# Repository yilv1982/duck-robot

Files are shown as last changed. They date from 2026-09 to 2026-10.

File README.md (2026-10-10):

# duck-robot

Microduck 小型双足机器人的个人复刻项目。**当前主线为方案 C（社区套件，飞特舵机路线，2026-10-09 定稿）**：选型采购、3D 打印、装配、系统部署与实机验证；强化学习训练在基础验证后再复现（方案 A 已存档，见下）。

进度流水、硬件到位记录与当前待办见 [PROGRESS.md](./PROGRESS.md)。

## 当前主线：方案 C（飞特路线）

- **执行机构**：飞特 HD-1910-C001 ×15（总线型，官方 robotd 有飞特补丁）
- **主控/总线**：microduck HAT（Radxa Zero 3W，板载 74LVC 半双工驱动接 UART2）+ imu_to_dxl v0.3 作总线从站（ID 200，双协议）
- **供电**：舵机/HAT/IMU 全部电池直通电压（电源板为可选转接件），拓扑见 [docs/power-architecture-v2.md](./docs/power-architecture-v2.md)
- **采购清单**：[BOM.md](./BOM.md)（已重写为 C 线；A 版存档于 [docs/bom-route-a-20260928.md](./docs/bom-route-a-20260928.md)）
- **PCB 打样**：[tools/jlc-order](./tools/jlc-order/README.md) —— 嘉立创开放平台全自动下单（计价→建单→审核→进度跟踪），2026-10-09 已实测下单并审核通过
- **IMU 刷机**：[flash/README.md](./flash/README.md)（DAPLink 接 J2 焊盘）
- 当前工作序列（IMU 刷机、banana_pcb 到板装配、舵机清点、HAT 验证）以 [PROGRESS](./PROGRESS.md) 待办为准；路线定稿理由与 C 线已知缺口见 PROGRESS「方案方向（2026-10-09）」。

## 并行参考库（只读）

三套开源资料按独立目录保存，**只读参考、不修改、不合并代码、硬件配置或采购清单**（2026-10-09 规则；历史混入的本地修改已提取到 [local-changes/](./local-changes/README.md)）：

| 方案 | 本地入口 | 参考内容 |
| :--- | :--- | :--- |
| A：帆哥教程 | [microduck-build-tutorial](./microduck-build-tutorial/README.md) | Pi Zero 2 W / OpenRB / XL330 路线（回退线，基线已存档） |
| B：fanhao375 复刻研究 | [microduck-replica](./microduck-replica/README.md) | 机械装配、电控与调试资料；兼论 XL330 与飞特路线 |
| C：jyg9 社区套件 | [microduck-community-kit](./microduck-community-kit/README.md) | **主参考**：imu_to_dxl / banana_pcb / dxl_hub 三块板、GD32 固件与升级工具、robotd 飞特补丁、HLS 舵机调试器 |

- 方案 B 遵循其 [LICENSE](./microduck-replica/LICENSE) 与 [NOTICE](./microduck-replica/NOTICE.md)：不同文件许可不同，不能整目录视为 Apache-2.0 或可商用；其打印 CAD 已迁往上游独立仓 [microduck-replica-cad](https://github.com/fanhao375/microduck-replica-cad)，本地 `cad/`、`print/` 不是完整打印包。
- 方案 C 缺口（`software/microduck_feetech/` 完整源码上游未推送、真机整定值仅可参考等）见 PROGRESS「方案方向」。

## 方案 A 回退线（存档）

A 线（XL330 + OpenRB + Pi Zero 2W）的完整步骤基线（阶段 0-7）、硬件约束（XL330/OpenRB 供电与板级电流限制）、仿真/镜像核查结论与 B 站视频笔记已整体移至 **[docs/route-a-baseline-20260928.md](./docs/route-a-baseline-20260928.md)**。相关入口：

- A 线 BOM 存档：[docs/bom-route-a-20260928.md](./docs/bom-route-a-20260928.md)
- 训练基线说明与验收证据：[docs/a-training.md](./docs/a-training.md)、[docs/a-training-validation.json](./docs/a-training-validation.json)
- 恢复 A 线训练环境前，需先把 [local-changes/microduck-build-tutorial/](./local-changes/microduck-build-tutorial/) 提取件按相对路径复制回位（`export_onnx.py` 内为旧机 WSL 路径，现机无 WSL，复用前须改写）。

## 致谢

感谢 [AI-FanGe/Microduck-build-tutorial](https://github.com/AI-FanGe/Microduck-build-tutorial)、[Rhoban/microban](https://github.com/Rhoban/microban)、[pollen-robotics/microduck](https://github.com/pollen-robotics/microduck) 及方案 B/C 上游作者的开源工作；各参考库内容以其自带许可为准。

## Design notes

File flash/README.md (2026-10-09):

# 刷机指南：把飞特固件烧进 ScrapMeta imu_to_dxl 板

目标板：**ScrapMeta `microduck-diy` imu_to_dxl v0.3**（32×22mm，丝印 `imu-to-dxl v0.3`，STM32G031F8P6 + LSM6DSV16X）——2026-10-09 用户确认手上绿板即此板。

要刷的固件：**replica 0.2.0 飞特版**（ID 200、@56 15 字节块、SCS/STS 协议）。预编译 HEX 已复制到本目录并通过作者公布的 SHA-256 校验（镜像 0x08000000 起 10,724 字节，`66bc7c53…938e`）。

> 引脚兼容性已逐脚核实（详见 `../docs/references/imu-to-dxl-variants-20261009/research.md`）：两板 PA0/PA1/PA2/PA3/PA4-7/PA11/PA12/PA13/PA14 功能一一对应；固件未用 INT2（ScrapMeta 板悬空无风险）；PB7 回显抑制脚在 ScrapMeta 板上是无害空操作。

---

## ⚠️ 供电红线（先读）

- 板上 LDO 是 **AP2210K-3.3，输入上限 5.5V**——这是 5V 供电设计。
- **刷机、调试、验收全过程中，VBATT 一律给 5V**（USB 5V 即可）。
- **绝对不要**把 2S 电池（7.2–8.4V）接到这块板的 VBATT——超 LDO 绝对最大值。将来在 8.4V 舵机总线上集成时，这块板的 VCC 必须从 5V 支路取电（与 jyg9 的 GD32 板 6–24V 输入不同）。

---

## 第 0 步：清点（你需要有什么）

| 物品 | 说明 | 没有？ |
|---|---|---|
| SWD 调试器 | **首选 CMSIS-DAP/DAPLink**（免驱）；ST-Link V2 也行（要装驱动，见排障） | 淘宝 ¥10–25 搜 "DAPLink" 或 "ST-Link V2" |
| SH1.0 7P 端子线 / BM07B 插座 | ⚠️ **实物板 J2 未焊插座，只有焊盘**（BM07B-SRSS-TB 是设计位号，出厂默认不贴）。方案 A：焊上 BM07B-SRSS-TB 座（约 ¥1-2）再插 SH1.0 7P 线（¥3，可复用）；方案 B：杜邦母对母线剪一头直接焊到 J2 焊盘（零采购，刷完剪掉） | 淘宝搜 "BM07B-SRSS-TB" / "SH1.0 7P 插头线" |
| 5V 电源 | USB 线（剪一头露出 +5V/GND）或面包板电源 | 现成的 USB 充电线即可 |
| 杜邦线母对母 | 4–6 根 | — |
| 万用表 | 核电压用 | — |

软件已全部备好（本目录）：OpenOCD 0.12.0、一键脚本、验收工具 imu200、Python 3.13 + pyserial（已装在 `C:\Users\elvis\AppData\Local\Programs\Python\Python313`）。**不需要装 Keil、不需要 ST 软件。**

## 第 1 步：接线（你做）

板子 **J2**（7P 调试座，板上丝印从 1 脚起：`3V3 / CLK / DIO / GND / TX / RX / RST`。⚠️ 实物板此处**未焊插座，只有焊盘**——按丝印把线逐根焊到焊盘上，或先焊上 BM07B-SRSS-TB 插座再用 SH 1.0 线）：

| J2 脚 | 丝印 | 接 DAPLink | 接 ST-Link V2 |
|---|---|---|---|
| 1 | 3V3 | **VTref**（电平参考，必接） | 3.3V 脚（作参考） |
| 2 | CLK | SWCLK | SWCLK |
| 3 | DIO | SWDIO | SWDIO |
| 4 | GND | GND | GND |
| 7 | RST | 可不接（连不上再接 NRST） | 同左 |
| 5/6 | TX/RX | 不接（验收阶段可选，见第 4 步） | 同左 |

板子供电（**J1**，EH 3P 总线座，丝印 GND/VBATT/DATA；J1/J3 并联插哪个都行）：

```
USB 5V  +  → J1-2 (VBATT)
USB 5V  −  → J1-1 (GND)
```

> 先用万用表确认你剪的 USB 线空载 5V 左右再接。接好后板上应有 3.3V（可用万用表量 J2-1 对 GND）。

**接好后的状态：DAPLink 插电脑 USB + 板子 5V 供电。**

## 第 2 步：烧录（你做，双击即可）

1. 双击 **`1-烧录-DAPLink.bat`**（ST-Link 用户用 `1-烧录-STLink.bat`）。
2. 看到这两行就是成功：
   ```
   ** Programming Started **
   ** Programming Finished **
   ** Verified OK **        ← 关键行
   ```
3. **给板子断电、再上电**（G0 芯片第一次烧写后的已知行为：软复位可能停在 ST 引导程序，断电重启一次即正常运行）。

脚本内容（其实就一条命令，出错时可直接看）：`openocd -f interface/cmsis-dap.cfg -c "adapter speed 200" -f target/stm32g0x.cfg -c init -c "reset halt" -c "program imu_to_dxl-0.2.0-feetech.hex verify" -c "reset run" -c shutdown`

## 第 3 步：接上总线（你做）

用 URT-2（或微雪转接板）做主机，跟板子对话：

```
URT-2 / 微雪适配器 TTL 总线三线 ──→ 板子 J1：
   GND  → J1-1 (GND)
   DATA → J1-3 (DATA)
   （VBATT 不从 URT-2 取，板子继续用自己的 USB 5V，共地即可）
```

URT-2 插电脑 USB，双击 **`2-查COM口.bat`** 找到它的 COM 号。

## 第 4 步：验收（你做，双击）

双击 **`3-验收-imu200.bat`**，输入 COM 号。它按主控真实代码的判据跑 **13 项检查**（ID 200 在线、@56 读 15 字节、四元数范数、陀螺量程、采样计数递增、不冻结、sync_read 时延……），全 PASS = 主控会认。

日志自动落在 `tools\imu200\logs\`（含原始收发十六进制），有问题把日志发我。

可选加分项：把 J2-5（TX）接任意 USB-TTL 的 RX（115200），能看到 replica 固件的调试日志。

## 排障

| 症状 | 处理 |
|---|---|
| DAPLink 方式报 `no CMSIS-DAP device found` | 换 USB 线/口（有些线只充电）；设备管理器看有没有 HID 设备 |
| ST-Link 报 `libusb_open() failed` / 找不到 | ST-Link 需要 WinUSB 驱动：装 [Zadig](https://zadig.akeo.ie/) → Options→List All Devices → 选 ST-Link → 目标驱动选 **WinUSB** → Replace Driver（约 30 秒）。换回 ST 官方软件时需重装 ST 驱动 |
| 连上但 `target halted` 报错/读不到 IDCODE | 检查 SWDIO/SWCLK 有没有接反；把 J2-7 (RST) 也接到调试器 NRST；脚本已用低速 200kHz，仍不行降到 100（编辑 bat） |
| `Programming Finished` 但 `Verified` 报错 | 重新烧一次；再不行把 bat 里 `verify` 后加 `reset halt` 前多等——一般不出现 |
| 验收某项 FAIL | 把 `tools\imu200\logs\` 最新日志发我，逐条判 |

## 文件清单

| 文件 | 说明 |
|---|---|
| `imu_to_dxl-0.2.0-feetech.hex` | 待刷固件（已过 SHA-256 校验；来源 replica 仓库 Build/，参考库只读所以复制出来） |
| `verify_hex.py` | 重跑完整性校验：`python verify_hex.py` |
| `1-烧录-DAPLink.bat` / `1-烧录-STLink.bat` | 一键烧录（program + verify + reset run） |
| `2-查COM口.bat` | 列串口 |
| `3-验收-imu200.bat` | 总线 13 项验收 |
| `tools/xpack-openocd-0.12.0-7/` | OpenOCD（xpack 构建，内置 stm32g0x 支持，无需器件包） |
| `tools/imu200/` + `tools/servo-web/` | 验收工具（来自 replica 仓库，复制出来用；`imu200.py demo` 可离线自测） |

## 边界（诚实清单）

- replica 0.2.0 固件**作者自述"真总线和舵机尚未实测"**（其主机测试与模拟总线验收全过，2026-09-22 已烧进其开发板工作正常）。本板刷完后 `imu200 check` 全 PASS 才算第一步验收；DE 释放时序、绝对 T_resp 等需逻辑分析仪的项可后置。
- 刷机会覆盖板上原有固件（ScrapMeta 的 DXL 2.0 版，如预刷过）；想刷回去：源码在参考库 `microduck-diy`（上游仓库），ScrapMeta 自带 `make g031` 构建与烧录脚本。
- 固件不写 Option Bytes、不写配置进 Flash（作者文档声明），刷写动作可逆、无 brick 风险（SWD 始终在）。

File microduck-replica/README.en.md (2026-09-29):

# Microduck Replica

**English** · [简体中文](README.md)

> A third-party reconstruction study of [Pollen Robotics' Microduck](https://pollen-robotics.com/microduck/).
> Assembly drawings, exploded views, CAD-importable assemblies, and a complete
> electronics teardown — all derived from publicly released files and source code.

Microduck is a 25 cm, 737 g bipedal robot duck driven by 15 Dynamixel XL330 servos
(14 under policy control) that learns to walk with reinforcement learning.

Its **software is open source (Apache-2.0)**. Its hardware is **partly** open:

- ✅ **The RPI Robot HAT board is fully published** — [`pollen-robotics/elec_RPI_Robot_HAT`](https://github.com/pollen-robotics/elec_RPI_Robot_HAT)
  (Apache-2.0): KiCad 9 project, Gerbers, BOM, pick-and-place and STEP. **You do not need to redraw this board.**
- ❌ **The `imu_to_dxl` board is not published** — no public project exists anywhere; the reconstruction
  in this repo is the only one available.
- ❌ **No editable mechanical CAD**, no whole-robot BOM, no assembly documentation. Pollen Robotics
  [told the press not to call it "open-source hardware" (for now)](docs/社区动态.md).

> 📌 **Correction (2026-09-03)**: this document previously stated "its hardware is not [open], no PCB
> schematics". **That was wrong** — it searched only `pollen-robotics/microduck` and missed the
> organisation's `elec_`-prefixed hardware repositories.

But two public artifacts turn out to be enough:

1. **`microduck_rl` ships the full MJCF model and 47 STL meshes.** The MJCF contains the
   complete kinematic tree — which part mounts to which, relative positions accurate to
   0.1 mm, joint axes, travel limits, masses and inertia tensors.
2. **The Rust runtime is open source, and a runtime that drives real hardware must
   hard-code device paths, I²C addresses, register offsets, baud rates and protocols.**
   The code *is* the datasheet.

This repository is what falls out of reading both.

> ✅ **Independently verified.** On 2026-08-31, [@tspy](https://x.com/tspy/status/2094249218735300630)
> published a hardware teardown on X (169 likes) that matches this repository's
> conclusions exactly — including the critical one: **the main board is a Radxa Zero 3W**.
> Two independent paths, one answer. See [Community Intelligence](docs/社区动态.md).

---

> **Models and print files: [microduck-replica-cad](https://github.com/fanhao375/microduck-replica-cad).** Select the Feetech or XL330 version there. Outdated printable STLs have been removed from this repository.

## Two tracks — pick one

This repository covers two servo choices. **Mechanics, electronics and software all differ**, so decide before building:

| | Original · Dynamixel XL330 | Feetech · HD-1910 |
|---|---|---|
| **Servos** | XL330-M288-T ×15 | HD-1910-C001 ×15 — half the price, 2.5× the torque |
| **Voltage** | rated 6 V, run at 6.6–8.2 V, **37% over** | rated 4–8.4 V, within spec; a full pack sits at the 8.4 V ceiling |
| **Printed parts** | [CAD repository · XL330](https://github.com/fanhao375/microduck-replica-cad) | [CAD repository · Feetech](https://github.com/fanhao375/microduck-replica-cad); mating parts are not interchangeable |
| **Editable CAD** | [CAD repo v1.1](https://github.com/fanhao375/microduck-replica-cad/releases/tag/v1.1) | [CAD repo v2.1](https://github.com/fanhao375/microduck-replica-cad/releases/tag/v2.1), files carry an `-FT` suffix |
| **Electronics** | official HAT + [`imu_to_dxl`](hardware/imu_to_dxl/) | same; servo connectors are 2.0 mm (official 2.5), `imu_to_dxl` has J4/J5 at 2.0 |
| **Software** | official runtime runs as-is | different bus protocol, swap the protocol module — [adaptation architecture](software/飞特适配架构.md) (zh); policy retrained for HD-1910 — [training data checklist](docs/HD-1910训练前数据清单.md) |
| **Status** | paper analysis + first prints | Assembled and stood up (09-18); **HAT received, camera capture passed on official B1** (09-28). Returning to the project image for retesting; mouth servo temporarily reassigned to ID 21 |

The selection argument is in [Actuator Selection](docs/actuator-selection.en.md). This repo's main line is Feetech; the original track is documented just as fully.

---

## Community

A WeChat group for people working on the same thing — build progress, pitfalls, sourcing.

The code below is for **Duck Replica Group 9** (WeChat disables QR joins once a group reaches 200 members).

<div align="center">
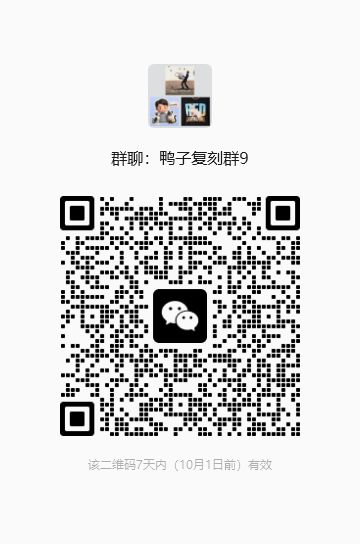
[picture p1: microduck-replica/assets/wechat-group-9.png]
Duck Replica Group 9 WeChat QR code
  
  <br>
  <sub><b>Duck Replica Group 9 · expires 2026-10-01</b> — WeChat group codes are valid for 7 days<br>
  If it has expired, open an <a href="https://github.com/fanhao375/microduck-replica/issues">issue</a> and I will post a fresh one</sub>
</div>

## Latest

**2026-09-28 — HAT and camera bring-up:** The HAT has arrived and been fitted to the board. After the camera ribbon orientation/contact was corrected, the Radxa Camera 8M219 was identified and **40 frames at 1920×1080** were captured on official Bookworm B1. The next step is to return to the project Armbian image and repeat the test with the corrected wiring. Sustained frame rate, all HAT functions and robot walking remain unverified. See the [wiring reference and test record](tools/radxa/摄像头调试记录-20260928.md) (Chinese).

<table>
<tr>
<td width="50%" valign="top">

### 🔌 Electronics · all 15 servos powered up in the assembled duck, and it stands (2026-09-18)

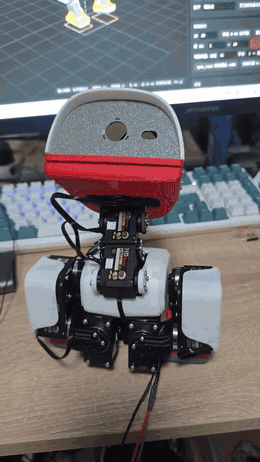
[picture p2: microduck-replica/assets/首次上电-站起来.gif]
First power-on: standing up from the tucked pose (click for the 30 s video)
<p align="center"></p>

First time the assembled duck was on the bus: URT-2 over USB, 7.4 V into V1, **all 15 HD-1910 online, 0 timeouts, 0 checksum errors**, one sync_read of 15 servos in 4.8 ms.
Driven from the new [web servo console](tools/servo-web/) in this repo: sliders, saved poses, sequences, a 3D model that follows the real robot and a live centre-of-mass marker against the foot support.
Above, it stands up from the tucked pose **by itself**, then sits back down. **First step of the Feetech software path works**; the hardware plan holds.

The above is the 09-18 test. As of 09-28, the failed ID 21 servo has been replaced with the former mouth servo (ID 34); the operator confirmed centre calibration at 2048, and the mouth is temporarily missing. The old “all 15 online” result is not the current configuration. Feetech-protocol [`imu_to_dxl` firmware 0.2.0](hardware/imu_to_dxl/firmware/) is available; physical bus testing is still pending.

**[Web servo console](tools/servo-web/)**　·　
**[Debug log](调试记录.md)** (zero pose, joint direction, stance pitfalls)　·　
[Pitfalls](踩坑记录.md#工具) (URT-2: USB first, then servo power)　·　
[Feetech adaptation architecture](software/飞特适配架构.md) (zh)

</td>
<td width="50%" valign="top">

### 🔨 Mechanical · Feetech HD-1910 build is assembled

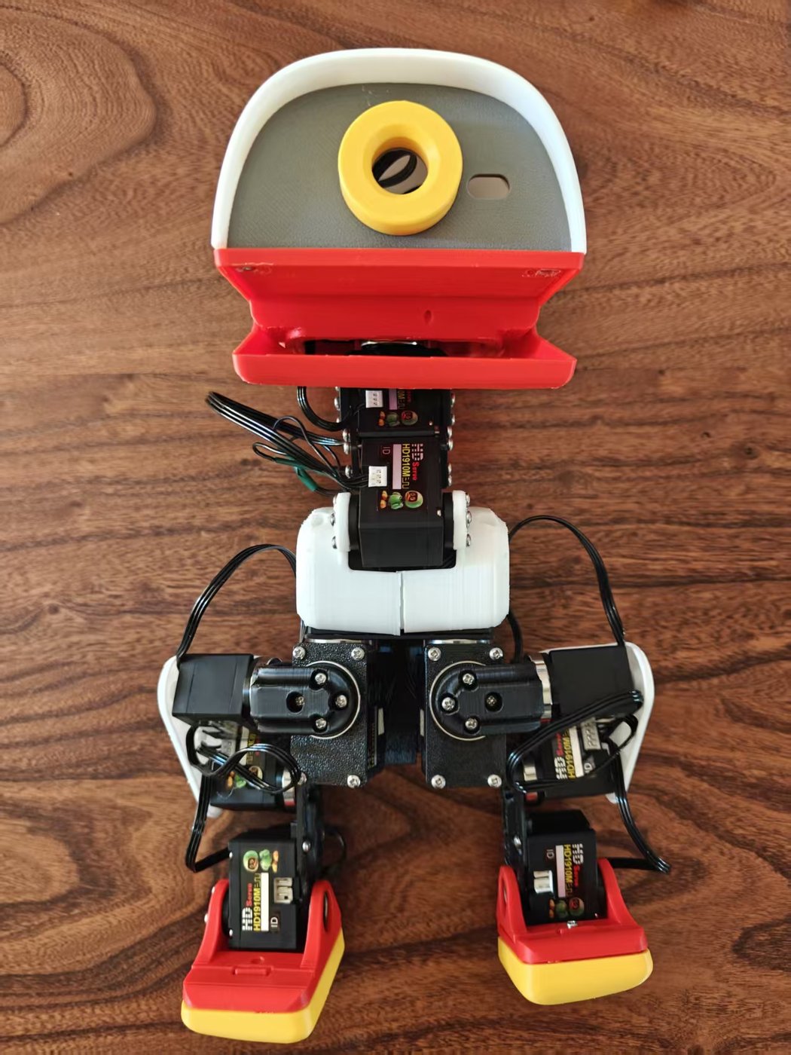
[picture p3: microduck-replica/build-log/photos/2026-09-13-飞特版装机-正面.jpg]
Feetech HD-1910 build


**All 15 Feetech HD-1910 servos configured and mounted.** Not the official XL330 — half the
price, 2.5× the torque, running inside its rated voltage; the path argued in
[Actuator Selection](docs/actuator-selection.en.md), now physical.

**The HD-1910 horn protrudes where the XL330's is recessed**, so the 8 parts that mate with
horns were remodelled and reprinted. The editable SolidWorks drawings have an FT variant
(`-FT` suffix) with what changed and why.

**[Build Log](BUILD-LOG.en.md)**　·
**[Feetech-variant SolidWorks drawings](https://github.com/fanhao375/microduck-replica-cad)**　·
**[Models and print files](https://github.com/fanhao375/microduck-replica-cad)**　·
[Debug Log](调试记录.md)　·
**[BOM with purchase links](https://github.com/fanhao375/microduck-replica-cad#装配-bom)**　·
[Print downloads](print/)
</td>
</tr>
<tr>
<td width="50%" valign="top">

### 💻 Software · web console driving 15 servos over the serial bus

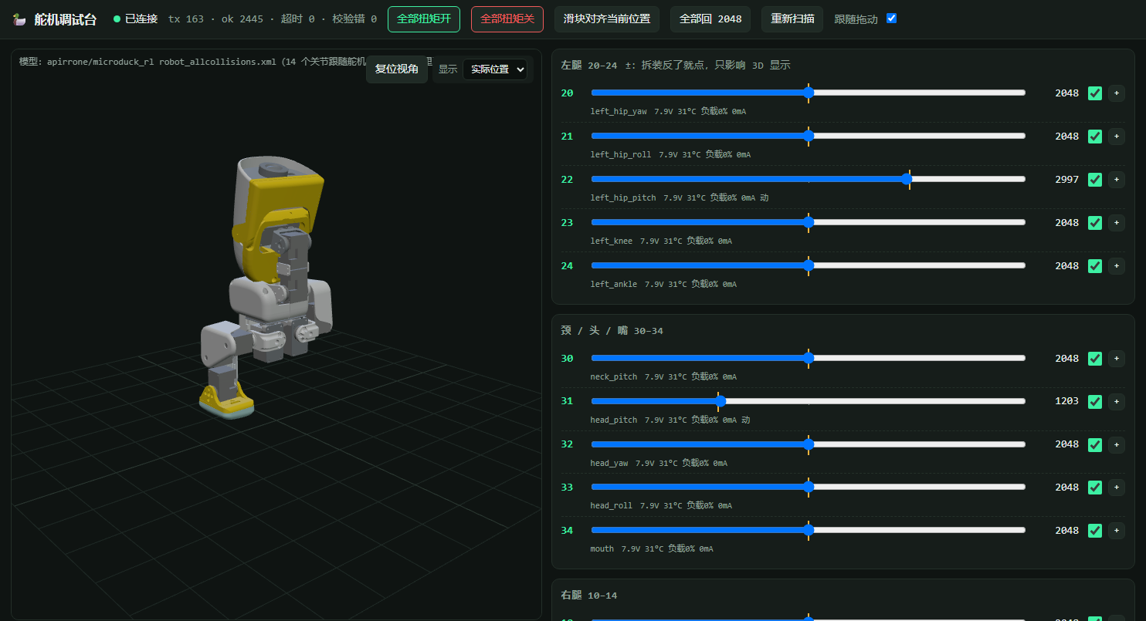
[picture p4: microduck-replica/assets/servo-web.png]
Web console: sliders, 3D duck, CoM projection
<p align="center"></p>

Drag a slider in the browser and the servo moves; the 3D duck follows, and the centre-of-mass
projection shows live whether it still falls inside the foot support polygon. Save poses, run
sequences, calibrate the zero in one click, dump every register, measure bus timing — this is the
tool used for assembly and bench acceptance.

The backend does not use the Feetech SDK: [`feetech.py`](tools/servo-web/feetech.py) speaks the
2026 protocol manual directly in about a hundred lines. It ships with a **packet-level servo
simulator**, so calibration, ID changes and register writes are self-tested with no hardware attached.

`FeetechIo` for the official runtime (the `RobotIo` seam, rustypot protocol v1) is written and
waiting on the zero calibration before it goes on the board.

**[Web console](tools/servo-web/)**　·　
**[Feetech port architecture](software/飞特适配架构.md)**　(Chinese)　·　
[Feetech official docs](docs/飞特资料/)

</td>
<td width="50%" valign="top">

### 🧠 Algorithms · public 1910 M6 parameter integration

The Feetech simulation baseline adopts the **1910 BAM M6 actuator parameters published by
[LuwuDynamics/xgoduck_rl](https://github.com/LuwuDynamics/xgoduck_rl)**. Thank you to LuwuDynamics
for sharing them. These parameters were not independently identified by this replica project.
The [provenance record](docs/HD-1910-M6参数来源.md) includes the pinned source revision,
original-file checksum and Apache-2.0 license.

The complete training project is included in **[`software/training/`](software/training/)**:
one clone includes the source, actuator parameters and simulation models. See the
[run guide and controller initialization fix](software/training/docs/hd1910-baseline.md).
Training builds on [Pollen Robotics/microduck_rl](https://github.com/pollen-robotics/microduck_rl)
and [Rhoban/BAM](https://github.com/Rhoban/bam). Integration tests and a short training check
have passed; there is no walking policy validated on this replica yet. Hardware testing still
needs joint calibration, IMU/runtime integration, and checks of actual mass/inertia and servo response.

**[HD-1910 pre-training data checklist](docs/HD-1910训练前数据清单.md)**　·　
[Actuator selection](docs/执行器选型.md)

</td>
</tr>
</table>

---

## 🔨 Build Progress

> This repository states repeatedly that simulation STLs are not manufacturing files.
> **The build log is the test of that claim.** The result gets recorded either way.

**→ [Build Log](BUILD-LOG.en.md)**

---

## 🦆 Contributions from the flock

This repo is not one person's work. Merged code and bench-verified findings are credited here.

| Who | What they contributed |
|---|---|
| [@yoyojacky](https://github.com/yoyojacky) | **A Rust test tool for Feetech servos** ([PR #27](https://github.com/fanhao375/microduck-replica/pull/27), merged). A minimal STS/SCS protocol implementation of his own (framing, checksum, ping, register read/write, status parsing). The CLI scans the bus with a progress bar, reads status, moves a servo to a position, and runs single or batch tests that report position error, peak current, peak load, voltage and temperature, with a PASS/FAIL verdict — one command gives you a bench acceptance table → [`tools/sts3215Servo_testtool/`](tools/sts3215Servo_testtool/) |
| [@Abo1ish](https://github.com/Abo1ish) | **IMU board firmware + attitude view in the debug console** ([PR #32](https://github.com/fanhao375/microduck-replica/pull/32), merged). A base STM32G031 firmware for the imu_to_dxl board that Pollen never open-sourced, verified on real hardware, with host-side tests and a [`VALIDATION.md`](hardware/imu_to_dxl/firmware/VALIDATION.md) that is clear about its limits → [`hardware/imu_to_dxl/firmware/`](hardware/imu_to_dxl/firmware/). He also streams the IMU attitude over J-Link into the web debug console, so the 3D duck's body turns with the real board (`--imu-jlink`, or `--imu-demo` with no hardware) → [`tools/servo-web/`](tools/servo-web/) |
| A member of the WeChat group | **Boot recipe for the Radxa Zero 3W V1.12J.** On this batch (WiFi changed to AIC8800DS2), swapping in Radxa's bootloader is not enough. He found by testing that the device tree has to come from Radxa too: **B1 bootloader + B1 DTB + Armbian 6.1.115 kernel + Trixie userland**, and got it booting → written up in the [pitfalls log](踩坑记录.md#软件) and the [image guide](tools/radxa/镜像使用说明.md) (both Chinese) |

### Projects from the flock

Some people build duck-related things in their own repos. The good ones get a shout-out here:

| Project | Author | What it does |
|---|---|---|
| [microduck-color-studio](https://github.com/LathamZ/microduck-color-studio) ([live demo](https://lathamz.github.io/microduck-color-studio/)) | [@LathamZ](https://github.com/LathamZ) | **A 3D color studio for the duck: settle the colors in your browser before you print.** Color each of the 70 parts, pick a material (PLA / matte / PETG / metallic / carbon fiber / TPU) and lighting to preview. Enter the filaments you already own and it recommends palettes from your stock (use what you have / add one color / acrylic accents). You can also import your own 3MF (e.g. the Feetech version) and export a **colored multi-plate 3MF** plus per-part STLs, with presets for Bambu P1S / A1 mini / H2D. Chinese and English UI, works on mobile |
| [MICDUCK_FTHD1901_REBUILD](https://github.com/fengj4780-sudo/MICDUCK_FTHD1901_REBUILD) | [@fengj4780-sudo](https://github.com/fengj4780-sudo) | **Feetech-build structural rework with optional CNC reinforcement.** Builds on our [editable SolidWorks drawings](https://github.com/fanhao375/microduck-replica-cad): adapted to the Feetech servo (written as HD1901 in that repo; the part files are HD-1910-C001), weak parts reinforced, assembly interferences fixed and some broken models repaired. **Five leg parts can be made as CNC parts** for better load paths (still being prototyped; the author estimates about ¥45 for all five including shipping); printing them instead also works and is stronger than the original. Includes a one-click 3MF (Bambu H2D, 0.4 mm, 5 plates) and the reworked SolidWorks drawings (Chinese) |

Built something for the duck (a tool, tutorial, mod, policy…)? Open an issue with the link and we'll add it.

Want to join in: open an [issue](https://github.com/fanhao375/microduck-replica/issues) or send a PR.
Hardware, firmware, algorithms, documentation, measured data — all of it counts. **Measured data especially**: the rule in this repo is that results get recorded honestly, positive or negative.

---

## Exploded Assembly View

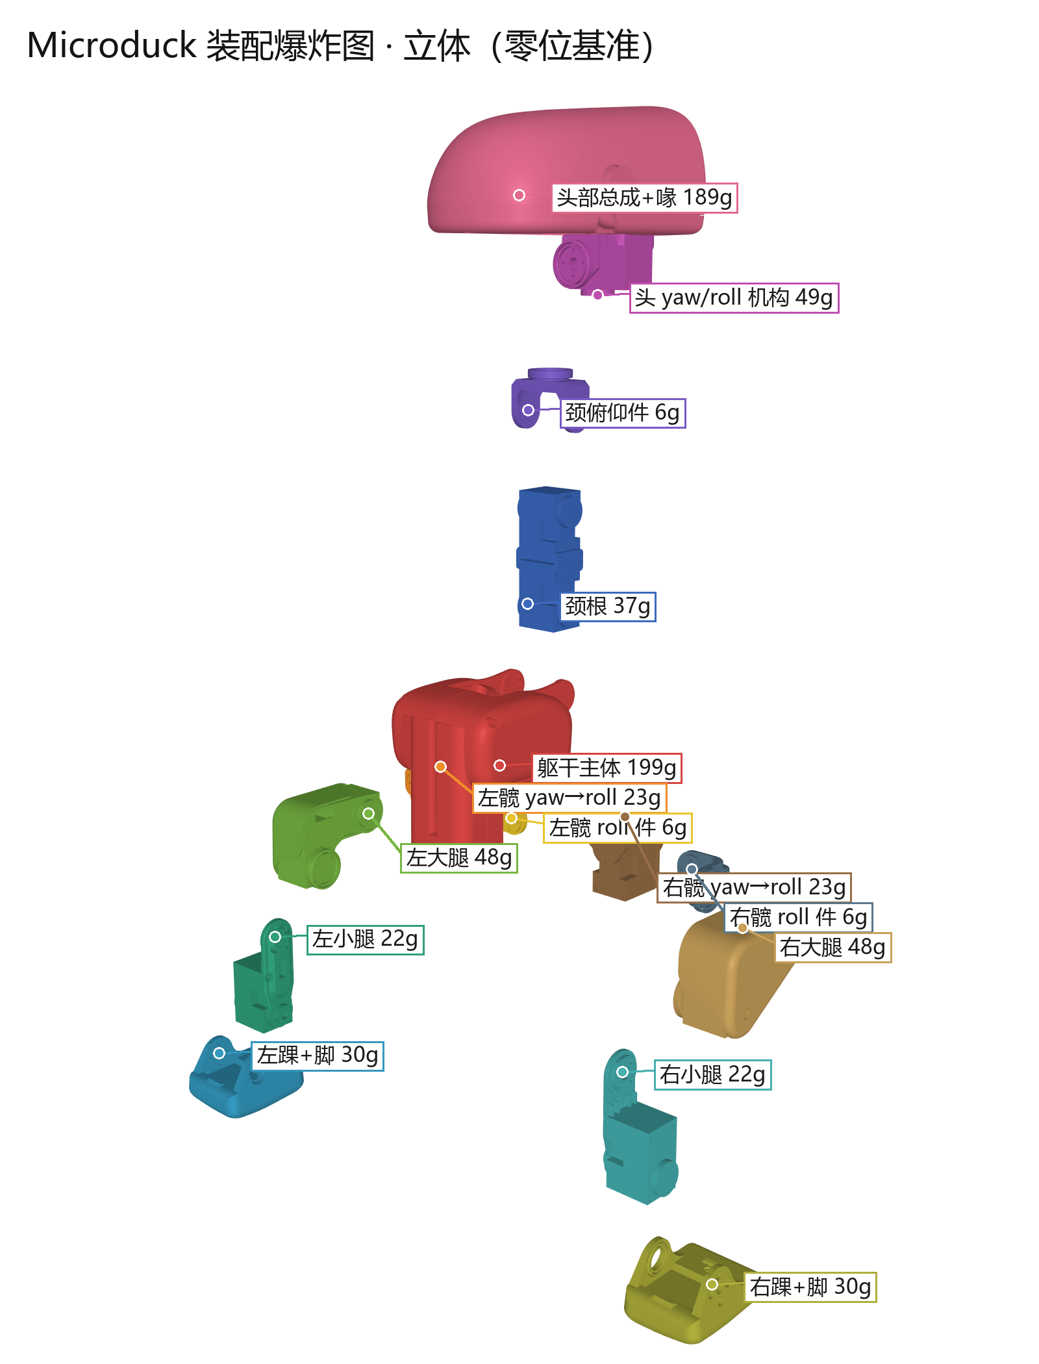
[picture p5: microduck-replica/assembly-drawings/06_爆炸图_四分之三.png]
Exploded view


Seven drawings under `assembly-drawings/`:

| File | Contents |
|---|---|
| `01_正面` `02_侧面` `03_背面` `04_四分之三` | Front / side / rear / isometric, assembled, natural colors |
| **`05_爆炸图_侧面`** | 15 parts exploded along the kinematic chain, labeled with names and masses |
| **`06_爆炸图_四分之三`** | Isometric — shows the left/right leg mirroring clearly |
| `07_分色对照_装配态` | Assembled state in the same color coding, for cross-reference |

## Assembly Structure

```
Trunk 199 g
├─ L hip yaw→roll 23 g → L hip roll 6 g → L thigh 48 g → L shin 22 g → L ankle+foot 30 g
├─ Neck base 37 g → Neck pitch 6 g → Head yaw/roll 49 g → Head assembly + beak 189 g
└─ R hip yaw→roll 23 g → R hip roll 6 g → R thigh 48 g → R shin 22 g → R ankle+foot 30 g

Total 737.2 g   Envelope 144 × 141 × 264 mm
```

The trunk and the head weigh almost the same (199 g vs 189 g) — **the head is a quarter of
the whole robot and the center of mass sits high**, which explains why its walking policy
is hard to train.

## Joint Parameters

Five DoF per leg, four for neck and head — **14 under policy control**.
The robot actually carries **15 Dynamixel XL330**: the 15th drives the beak through a
passive linkage and never enters the action space.

| Joint | Travel |
|---|---|
| `hip_yaw` | −25° … +30° |
| `hip_roll` | ±22° |
| `hip_pitch` / `knee` / `ankle` / `head_pitch` | ±90° |
| `neck_pitch` | −90° … +60° |
| `head_yaw` | ±170° |
| `head_roll` | ±25° |

## 📋 Bill of Materials

**What to buy and how many** — [`BOM.en.md`](BOM.en.md)

15 servos, 14 bearings, ~325 fasteners, 2 boards to fabricate. Quantities are counted from geom
references in the upstream MJCF (38 mesh types / 75 instances), not estimated. Includes a per-board
parts list with LCSC numbers.

> ⚠️ Two corrections in there that stop you buying the wrong thing: **the battery is an NP-F550,
> not an F970**, and **the XL330 is run over-voltage**.

## Print files and CAD assemblies

**Download models from [fanhao375/microduck-replica-cad](https://github.com/fanhao375/microduck-replica-cad).** SolidWorks, STEP, print projects, assembly BOMs and installation instructions are maintained together there.

| Servo version | CAD release checked on 2026-09-28 |
|---|---|
| Feetech HD-1910 | [v2.1](https://github.com/fanhao375/microduck-replica-cad/releases/tag/v2.1) |
| Dynamixel XL330 | [v1.1](https://github.com/fanhao375/microduck-replica-cad/releases/tag/v1.1) |

The old `print/` parts and `cad/` assembly STLs came from upstream simulation geometry and did not include the physical CAD changes. Those files have been removed; the directories now contain download pointers. **Do not mix the two servo versions or print simulation/web-viewer meshes from this repository.**

The CAD repository's older 09-15 3MF does not include the v2.1 combined wheel. Check the attachment version; see [printing notes](print/README.en.md). CAD modelling and assembly documentation are by **机械行者Robo**, with attribution and licensing in the CAD repository.

---

## Electronics, Reverse-Engineered from the Runtime

<div align="center">
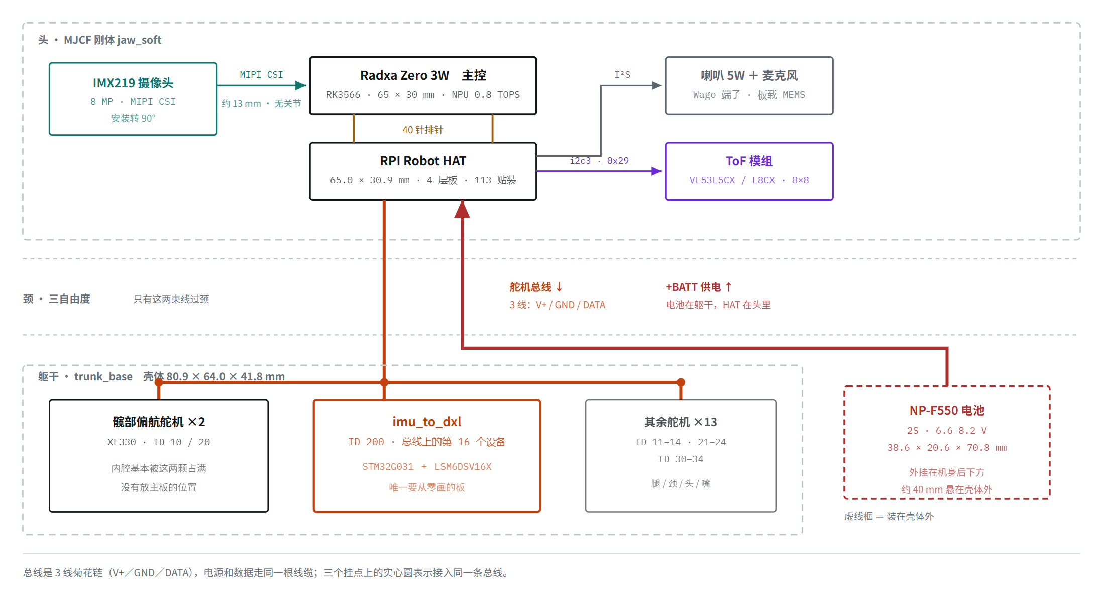
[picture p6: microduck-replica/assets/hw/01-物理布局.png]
Microduck electronics overview: where each board sits
  
  <br>
  <sub><b>Physical layout of the five modules.</b> Dashed grey = physical region, solid = module,
  dashed red = mounted <b>outside</b> the shell.<br>
  <b>Orange</b> is the servo bus (top-down), <b>red</b> is battery power (bottom-up).<br>
  The one thing people get wrong: <b>the compute board, the HAT and the camera are all in the head</b> —
  the camera sits ~13 mm from the board centre with no joint between them,<br>
  so the MIPI ribbon never crosses the neck. What does cross it is the servo bus and the power line.<br>
  <a href="docs/硬件入门.md">Full diagram set (Chinese) →</a>　·　<a href="assets/hw/Microduck硬件图集.pdf">Download PDF (7 diagrams, A3)</a></sub>
</div>

**One 1 Mbps TTL serial bus does everything.**

```
                Radxa Zero 3W (RK3566) · Armbian
                  ├── UART2  1 Mbps TTL half-duplex ── 15× XL330 + imu_to_dxl (ID 200)
                  ├── I2C3   400 kHz (pins 3/5) ────── AIC3104@0x18 · ToF@0x29 · BMI088 (unused)
                  ├── I2S3   12.288 MHz ────────────── audio
                  ├── MIPI CSI ─────────────────────── IMX219 (I2C@0x10, mounted upside down)
                  ├── Bluetooth ────────────────────── gamepad / phone app
                  ├── Wi-Fi ────────────────────────── WebRTC
                  └── USB-C ────────────────────────── power + maskrom
```

| | |
|---|---|
| **Main board** | **Radxa Zero 3W** — an off-the-shelf module, *not* a custom carrier |
| SoC | RK3566, quad Cortex-A55, Mali-G52, 0.8 TOPS NPU, 1 GB RAM / 32 GB eMMC |
| **Servo bus** | **Single-wire half-duplex TTL** — *not* RS-232, *not* RS-485. Dynamixel Protocol V2 @ 1 Mbps on `/dev/ttyS2` |
| **Custom board 1** | **`imu_to_dxl` v2** — an LSM6DSV16X that speaks Dynamixel: bus ID 200, register 124, a 12-byte block read in the *same* `sync_read` as the servos |
| **Custom board 2** | **RPI Robot HAT** — TLV320AIC3104 @ 0x18, a dormant BMI088, a Stemma header for the ToF. **Published by Pollen** ([`elec_RPI_Robot_HAT`](https://github.com/pollen-robotics/elec_RPI_Robot_HAT)) |
| Battery | Sony NP-F550, 2S Li-ion. **No fuel gauge, no ADC** — pack voltage is read from what the servos report as their own supply |
| Sensors | LSM6DSV16X IMU · VL53L5CX/L8CX 8×8 ToF · IMX219 (Pi Camera v2) |

The `imu_to_dxl` design is the elegant part: the IMU is not on I²C. It presents itself as a
Dynamixel slave, so orientation arrives in the same bus transaction as the joint states —
no second bus, no host-side sensor fusion (the LSM6DSV16X's on-chip SFLP block emits a game
rotation quaternion and estimates its own gyro bias).

**Full detail:** [Hardware Teardown](docs/hardware-teardown.en.md) (English) ·
[Spec Sheet](docs/硬件规格速查.md) (Chinese)

---

## Can You Actually Build One?

| | Status |
|---|---|
| Part geometry | ✅ 47 STLs |
| Assembly relationships | ✅ 0.1 mm accurate, drawings produced |
| Joint axes / travel | ✅ all 14 |
| Mass / inertia | ✅ all 15 bodies |
| Servo model | ✅ Dynamixel XL330 × 15 |
| Bearings | ✅ Ø22×16×4 and Ø15×10×3 |
| Battery / sensors | ✅ NP-F550 2S, IMX219, VL53L8CX, LSM6DSV16X |
| Main board | ✅ **Radxa Zero 3W, off the shelf** |
| **HAT board** | ✅ **Officially published** — KiCad + Gerbers + BOM → [`elec_RPI_Robot_HAT`](https://github.com/pollen-robotics/elec_RPI_Robot_HAT) |
| **`imu_to_dxl` board** | ⚠️ Not published; must be redrawn. Protocol and register layout fully recovered |
| **Fastener list** | ✅ Reverse-engineered from hole features → M2 system |
| **Cable routing** | ❌ Nothing published |
| Control software | ⚠️ Rust runtime is Apache-2.0 and **runs as-is on the same main board** |

⚠️ **Simulation STLs are not manufacturing files.** Simulation only needs outer shape and
inertia — it guarantees nothing about fit tolerances, threads, heat-set insert bosses or
cable clearance. Printing these directly will most likely not assemble.

💰 **Building one probably costs more than buying one — but how much more depends entirely on
your channel.** Fifteen XL330s run about **$359** at ROBOTIS international, **$412** at ROBOTIS US,
and **€603–629** in Europe inc-VAT — anywhere from slightly under the robot's retail price to well
above it. Add the compute module, battery, two boards to fabricate and filament, and it is certainly
more. Full costing: [BOM.en.md](BOM.en.md).

**The conclusion has been revised** from "the mechanics are copyable, the electronics are a wall"
to **"the whole robot is reproducible"** — the main board is an off-the-shelf module, and the custom
boards' function and protocol have been fully recovered from source.
See [Hardware Teardown](docs/hardware-teardown.en.md).

---

## The Realistic Path

Skip 100% replication and go **"copy the mechanics, build your own electronics"**:

| | Approach |
|---|---|
| Mechanics | Select the matching servo version in the [CAD repository](https://github.com/fanhao375/microduck-replica-cad) |
| Servos | XL330 × 15, off the shelf |
| Main board | **Radxa Zero 3W**, same as the original |
| IMU board | Roll your own `imu_to_dxl`: LSM6DSV16X + a small MCU + half-duplex transceiver. The protocol is fully documented here |
| HAT | **Order the official Gerbers** (4-layer); or skip it entirely if you don't need audio |
| Software | Same main board → the official Rust runtime runs unmodified |
| Policies | The nine shipped ONNX policies work; retrain with [microduck_rl](https://github.com/pollen-robotics/microduck_rl) if you change hardware |

## Three Pitfalls Worth Knowing

1. **Armbian runs a login console on UART2.** `serial-getty@ttyS2` holds the port —
   `systemctl mask` it. Pollen found this with `fuser -v /dev/ttyS2`.
2. **i2c3 collides with the FUSB302.** Using the hardware I²C on header pins 3/5 costs you
   USB-C PD negotiation (plain 5 V charging still works).
3. **The NPU ships disabled** in Armbian — flash the overlay and reboot to run RKNN models.

---

## Ecosystem Map

Microduck material is scattered across several GitHub orgs and three HuggingFace resource types —
**the official hardware repos are especially easy to miss**. [`docs/ecosystem.en.md`](docs/ecosystem.en.md)
annotates every official repo, simulator, policy, dataset and community project with what it is and
what it is good for.

## Documentation

| Document | Contents |
|---|---|
| [**Hardware Spec Sheet**](docs/硬件规格速查.md) | One-page reference — block diagram, part numbers, bus parameters, build list, pitfalls |
| [**Hardware Primer**](docs/硬件入门.md) | **Board by board** — what each of the five modules does, how one 20 ms control tick flows, what changes on the Feetech route, and a closing section on **five checks to run before you replicate** |
| [**Electronics Sourcing (CN)**](docs/电控采购清单.md) | Taobao links with verified availability — main board, camera, ToF, power, both PCBs, cabling and the debug adapter |
| [**Mechanical Sourcing (CN)**](docs/机械采购清单.md) | Bearings, M2 fasteners, heat-set inserts and the insertion tip, thread locker, filament |
| [**Hardware Teardown**](docs/hardware-teardown.en.md) 🇬🇧 | **Full derivation with evidence citations — the main board, both custom boards, bus protocol, sensors, power** |
| [**Actuator Selection**](docs/actuator-selection.en.md) 🇬🇧 | XL330 parameters, BAM M6 config, five calibrated PD sets, backlash modeling — plus **why closed-loop steppers do not work here, what swapping to a Feetech STS3215 actually costs** (737 g vs 2107 g, measured), and a **cross-comparison of same-class servos** including a deep assessment of the Unitree S288 |
| [**Fastener Reconstruction**](docs/fastener-reconstruction.en.md) 🇬🇧 | Hole-feature scan across 47 STLs → M2 system and purchase quantities |
| [Community Intelligence](docs/社区动态.md) | X / GitHub signals, independent verification, noise and scam warnings |
| [Progress](PROGRESS.md) | Status, decisions, open work |

> 🇬🇧 marks documents available in English. The rest are Chinese-only for now — their
> tables, part numbers, addresses and diagrams are readable without it, and machine
> translation handles the prose well.

## Reproducing This

```bash
# 1. Fetch upstream for the drawing scripts below (training is already in software/training/)
bash scripts/fetch_upstream.sh

# 2. Regenerate the drawings
python scripts/render_assembly.py upstream/microduck_rl assembly-drawings

# 3. Export upstream assembly previews for analysis (not manufacturing)
python scripts/export_assembly_stl.py upstream/microduck_rl analysis-output/cad-upstream

# 4. Re-scan hole features
python scripts/analyze_holes.py upstream/microduck_rl/src/mjlab_microduck/robot/microduck/assets
```

Requires `mujoco`, `numpy`, `pillow`, `scipy`. Rendering needs a working OpenGL context.

## License

- `scripts/` — Apache-2.0
- `assembly-drawings/` and retained simulation meshes — **CC BY-SA-NC 4.0**. Upstream 3D models are CC BY-SA-NC;
  ShareAlike requires derivatives to carry the same license. **Non-commercial only.**

See [NOTICE.md](NOTICE.md). Not affiliated with or endorsed by Pollen Robotics.

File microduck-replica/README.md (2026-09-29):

# Microduck 复刻

**简体中文** · [English](README.en.md)

> **模型与打印文件统一入口：[microduck-replica-cad](https://github.com/fanhao375/microduck-replica-cad)。** 飞特 / XL330 请选对应版本；本仓旧打印 STL 已移除，避免误打。

> 对 [Pollen Robotics Microduck](https://pollen-robotics.com/microduck/) 的第三方复刻研究。
> 从官方公开的 MJCF 仿真模型反推出**装配图、爆炸图和可直接导入 CAD 的装配体**。

Microduck 是一只 25cm 高、737g 的双足机器鸭，15 个 Dynamixel XL330 舵机（14 个受策略控制），用强化学习走路。
它的**软件开源（Apache-2.0）**。硬件是**部分开源**：

- ✅ **RPI Robot HAT 板完整开源** —— 见 [`pollen-robotics/elec_RPI_Robot_HAT`](https://github.com/pollen-robotics/elec_RPI_Robot_HAT)（Apache-2.0）：
  KiCad 9 工程、Gerber、BOM、贴片坐标、STEP 一应俱全。这块板**不需要自己画**。
- ❌ **`imu_to_dxl` 板未开源** —— 全网无公开工程，本仓库的逆向是目前唯一公开重建。
- ❌ **机械件无可编辑 CAD**、无 BOM、无装配文档。

> 📌 **勘误（2026-09-03）**：本文档此前写作「硬件不开源、没有 PCB 原理图」，**这是错的**。
> 当时只检索了 `pollen-robotics/microduck` 主仓，未翻查该组织下以 `elec_` 开头的硬件仓库。

但官方在 `microduck_rl` 里发布了完整的 **MJCF 仿真模型 + 47 个 STL 网格**。
MJCF 里包含了完整的运动学树：每个零件挂在谁身上、相对位置精确到 0.1mm、
绕哪根轴转、行程多少、质量和惯量张量。

**这些信息足以还原出装配关系。** 本仓库就是把它还原出来的结果。

---

## 两条路线，选一条走

本仓库同时覆盖两种舵机。**机械、电路、软件三层都有差别**，动手前先定：

| | 原版 · Dynamixel XL330 | 飞特 · HD-1910 |
|---|---|---|
| **舵机** | XL330-M288-T ×15 | HD-1910-C001 ×15 —— 便宜一半、力矩 2.5 倍 |
| **电压** | 额定 6 V，实跑 6.6–8.2 V，**超压 37%** | 额定 4–8.4 V，在额定内；但满电 8.4 V 顶格 |
| **打印件** | [CAD 仓库 · XL330 版](https://github.com/fanhao375/microduck-replica-cad#两个版本选一个下) | [CAD 仓库 · 飞特版](https://github.com/fanhao375/microduck-replica-cad#两个版本选一个下)，舵盘配合件不能混用 |
| **可编辑图纸** | [图纸仓 v1.1](https://github.com/fanhao375/microduck-replica-cad/releases/tag/v1.1) | [图纸仓 v2.1](https://github.com/fanhao375/microduck-replica-cad/releases/tag/v2.1)，文件带 `-FT` 后缀 |
| **电路** | 官方 HAT + [`imu_to_dxl`](hardware/imu_to_dxl/) | 同左；舵机连接器 2.0 mm（官方 2.5），`imu_to_dxl` 板上 J4/J5 是 2.0 |
| **软件** | 官方运行时直接跑 | 总线协议不同，要换协议模块 —— [适配架构分析](software/飞特适配架构.md)；策略要按 HD-1910 重训 —— [训练前数据清单](docs/HD-1910训练前数据清单.md) |
| **状态** | 纸上分析 + 首批打印件 | 已装机并站起（09-18）；**HAT 到货、官方 B1 下摄像头出图**（09-28），准备换回项目镜像复测；嘴舵机暂挪作 ID 21 |

选型论证在 [执行器选型](docs/执行器选型.md)。本仓库主线走飞特；原版资料同样齐全，两条都能复刻。

---

## 交流群

有人在做同样的事，凑了个微信群一起讨论复刻进度、踩过的坑、元件采购。

下面是**鸭子复刻群 9**的二维码（微信群满 200 人后无法扫码加入）。

<div align="center">
  鸭子复刻群 9 微信二维码
  <br>
  <sub><b>鸭子复刻群 9 · 二维码有效期到 2026-10-01</b>（微信群码 7 天自动失效）<br>
  过期了请开个 <a href="https://github.com/fanhao375/microduck-replica/issues">issue</a> 说一声，我会换上新的</sub>
</div>

## 最近更新

**2026-09-28 · HAT 与摄像头调试**：HAT 已到货并与主板对插；Radxa Camera 8M219 起初在两个系统下都识别失败，调整排线正反面后，官方 B1 成功读到 IMX219 并采集 **40 帧、1920×1080** 图像。下一步换回原项目 Armbian 镜像，用正确接线复测；本次是短测，尚未验收持续帧率、HAT 全功能或整机行走。**[接线参考图与复测记录](tools/radxa/摄像头调试记录-20260928.md)** · **[踩坑记录](踩坑记录.md#主板--hat--摄像头)**。

**IMU 姿态接入调试台**：[`tools/servo-web/`](tools/servo-web/) 可选接入 J-Link，在同一个 3D 鸭子上显示舵机关节角与 IMU 躯干姿态。配套固件在 [`hardware/imu_to_dxl/firmware/`](hardware/imu_to_dxl/firmware/)，**0.2.0 已改成飞特协议**（ID 200、地址 56、15 字节），电脑上验收全过，等整机上真总线实测；没有 J-Link 也能用 ST-Link / DAPLink（`--imu-swd`）或直接走舵机总线（`--imu-bus`）看姿态。

<table>
<tr>
<td width="50%" valign="top">

### 🔌 电气 · 15 颗舵机整机上电，站起来了（2026-09-18）

<p align="center"><a href="assets/首次上电-2026-09-18.mp4">第一次上电：从缩着站起来（点开看 30 秒视频）</a></p>

装好的鸭子第一次接总线：URT-2 走 USB、7.4 V 进 V1，**15 颗 HD-1910 全部在线，0 超时 0 校验错**，一次同步读 15 颗 4.8 ms。
用仓库里新写的[网页调试台](tools/servo-web/)拖滑块、存姿态、跑序列，3D 模型跟着真机动，重心投影实时显示在不在脚底范围。
上面这段是它从缩着**自己站起来**再坐下。**飞特路线的软件第一步走通了**，硬件方案没问题。

以上是 09-18 的上电记录。09-28 本机原 ID 21 已损坏，嘴 ID 34 的舵机挪作 ID 21，用户确认 FD 校中位到 2048，嘴暂缺；当前不能沿用“15 颗全在线”作为验收结论。`imu_to_dxl` 已有飞特协议 [0.2.0 固件](hardware/imu_to_dxl/firmware/)，真总线仍待测。

**[网页调试台](tools/servo-web/)**　·　
**[调试记录](调试记录.md)**（零位、方向、站姿的坑）　·　
[踩坑记录](踩坑记录.md#工具)（URT-2 先插 USB 再上电）　·　
[飞特适配架构](software/飞特适配架构.md)

</td>
<td width="50%" valign="top">

### 🔨 机械 · 飞特 HD-1910 版装出来了

<a href="构建日志.md">飞特 HD-1910 版装机实物</a>

**15 颗飞特 HD-1910 全部配好 ID、装进机身。** 这不是官方的 XL330 —— 便宜一半、力矩大 2.5 倍、
电压额定匹配，是[执行器选型](docs/执行器选型.md)里论证的那条路，现在有实物了。

**HD-1910 的舵盘是凸的，XL330 是凹的**，跟舵盘配合的 8 个件同事全改了、重新打印。
可编辑的 SolidWorks 图纸也出了飞特版（`-FT` 后缀），改了什么、为什么，
在图纸仓里写清楚了。

**[构建日志](构建日志.md)**　·
**[飞特版 SolidWorks 图纸](https://github.com/fanhao375/microduck-replica-cad)**　·
**[模型与打印文件](https://github.com/fanhao375/microduck-replica-cad)**　·
**[BOM 清单 · 带采购链接](https://github.com/fanhao375/microduck-replica-cad#装配-bom)**　·
[调试记录](调试记录.md)　·
[打印入口](print/)
</td>
</tr>
<tr>
<td width="50%" valign="top">

### 💻 软件 · 网页调试台，串口直连 15 颗舵机

<p align="center"><a href="tools/servo-web/">网页调试台：滑块、3D 鸭子、重心投影</a></p>

浏览器拖滑块让舵机动，3D 鸭子跟着转，重心投影实时算在不在脚底范围。
存姿态、跑序列、一键校准零位、导出全部寄存器、时序测试，装机和台架验收都用它。

后端不依赖飞特 SDK，[`feetech.py`](tools/servo-web/feetech.py) 按 2026 版协议手册直接收发包，一百多行。
配套一个**协议级舵机模拟器**，不接硬件就能把校准、改 ID、写寄存器跑一遍自检。

接官方运行时的 `FeetechIo`（`RobotIo` 接缝，rustypot 协议 v1）已经写完、跟上了官方 0.14.1，等零位校准做完上板 —— 代码在 fork 的 **[`feetech` 分支](https://github.com/fanhao375/microduck/tree/feetech)**。

**[网页调试台](tools/servo-web/)**　·
**[飞特适配架构](software/飞特适配架构.md)**　·
**[FeetechIo 代码](https://github.com/fanhao375/microduck/tree/feetech)**　·　
[飞特官方资料](docs/飞特资料/)（协议、内存表）

</td>
<td width="50%" valign="top">

### 🧠 算法 · 接入公开的 1910 M6 参数

采用 **[LuwuDynamics/xgoduck_rl](https://github.com/LuwuDynamics/xgoduck_rl) 公开的 1910 BAM M6 动力学参数**，
作为飞特版的仿真训练基线。感谢 LuwuDynamics 的分享；这份参数不是我们自行辨识的结果。
出处、固定版本、原文件校验值和 Apache-2.0 许可见[参数来源说明](docs/HD-1910-M6参数来源.md)。

完整训练工程已放入本仓库 **[`software/training/`](software/training/)**，一次克隆即可取得
代码、参数和仿真模型；[运行说明与初始化修复解释](software/training/docs/hd1910-baseline.md)给出具体命令。
训练沿用 [Pollen Robotics/microduck_rl](https://github.com/pollen-robotics/microduck_rl) 和
[Rhoban/BAM](https://github.com/Rhoban/bam)。已通过接入测试和短训练检查，尚无本机实测通过的走路策略。
实机测试仍需完成**零位、关节方向、IMU 和主控接入**，并核对本机质量惯量与舵机响应。

**[HD-1910 训练前数据清单](docs/HD-1910训练前数据清单.md)**　·
[执行器选型](docs/执行器选型.md)

</td>
</tr>
</table>

---

## 🔨 实物进度

> 本仓库反复强调「仿真 STL 不是可打印工程件」。**构建日志就是在验证这句话。**
> 结论会如实记录，无论正反。

**→ [构建日志](构建日志.md)**（机械）　·　**[调试记录](调试记录.md)**（电气与软件）　·　**[踩坑记录](踩坑记录.md)**

---

## 🦆 鸭友贡献

这个仓库不是一个人写的。合并进来的代码、实测验证过的结论，都记在这儿。

| 谁 | 贡献了什么 |
|---|---|
| [@yoyojacky](https://github.com/yoyojacky) | **Rust 版飞特舵机测试工具**（[PR #27](https://github.com/fanhao375/microduck-replica/pull/27)，已合并）。自己实现的最小 STS/SCS 协议（帧打包、校验和、ping、读写寄存器、状态解析），命令行可以扫描总线（带进度条）、读状态、转到指定位置、单颗测试和批量测试，输出位置偏差、峰值电流、峰值负载、电压温度并判定 PASS/FAIL。台架验收一条命令出汇总表 → [`tools/sts3215Servo_testtool/`](tools/sts3215Servo_testtool/) |
| [@Abo1ish](https://github.com/Abo1ish) | **IMU 小板固件 + 调试台姿态显示**（[PR #32](https://github.com/fanhao375/microduck-replica/pull/32)，已合并）。给官方没开源的那块 imu_to_dxl 写了 STM32G031 固件底子，在实板上验证过，带主机端测试和一份写清楚边界的 [`VALIDATION.md`](hardware/imu_to_dxl/firmware/VALIDATION.md) → [`hardware/imu_to_dxl/firmware/`](hardware/imu_to_dxl/firmware/)；再用 J-Link 把 IMU 姿态实时读出来并进了网页调试台，3D 鸭子的躯干跟着真板子转（`--imu-jlink`，没板子也能用 `--imu-demo` 先看效果）→ [`tools/servo-web/`](tools/servo-web/) |
| 微信群的鸭友 | **Radxa Zero 3W V1.12J 的启动方案**。这批板子（WiFi 换成 AIC8800DS2）光换瑞莎引导还是起不来，他实测出设备树也得换成瑞莎 B1 的：**B1 引导 + B1 DTB + Armbian 6.1.115 内核 + Trixie 系统**，跑通了 → 写进了[踩坑记录](踩坑记录.md#软件)和[镜像使用说明](tools/radxa/镜像使用说明.md#6-如果你的板子不是这一批) |

### 鸭友的项目

有些鸭友是自己单独开仓库做的，不在这个仓库里，但跟鸭子直接相关、做得好的，放这儿推一下：

| 项目 | 作者 | 做什么的 |
|---|---|---|
| [microduck-color-studio](https://github.com/LathamZ/microduck-color-studio)（[在线试用](https://lathamz.github.io/microduck-color-studio/)） | [@LathamZ](https://github.com/LathamZ) | **鸭子的 3D 配色工作室，打印前先在网页里把颜色定好。** 70 个零件逐件上色，选材质（PLA / 哑光 / PETG / 金属 / 碳纤 / TPU）和灯光看效果；填上自己手里有哪些耗材，它按库存推荐配色（只用已有 / 补一色 / 丙烯点缀）。还能导入自己的 3MF（比如飞特版），导出**带颜色的多盘 3MF** 和按件拆好的 STL，拓竹 P1S / A1 mini / H2D 有预设。中英文界面，手机上也能看 |
| [MICDUCK_FTHD1901_REBUILD](https://github.com/fengj4780-sudo/MICDUCK_FTHD1901_REBUILD) | [@fengj4780-sudo](https://github.com/fengj4780-sudo) | **飞特版结构改进 + 可选 CNC 加强件。** 在我们的[可编辑 SolidWorks 图纸](https://github.com/fanhao375/microduck-replica-cad)基础上接着改：适配飞特舵机（他仓库里写作 HD1901，零件文件用的是 HD-1910-C001），加强了薄弱件，修了装配干涉和几个破损的模型。腿部 **5 个零件可以换成 CNC 件**让受力更合理（还在打样测试，他估算 5 件含运费约 45 元）；不做 CNC 直接打印也行，强度也比原版好。附一键打印的 3MF（拓竹 H2D、0.4 mm、5 盘）和改好的 SolidWorks 图纸 |

做了跟鸭子有关的项目（工具、教程、改装、策略……），开 issue 贴个链接，我们加进来。

想加进来：直接开 [issue](https://github.com/fanhao375/microduck-replica/issues) 或提 PR。
硬件、固件、算法、文档、实测数据都算 —— **实测数据尤其欢迎**，这个仓库的规矩是结论如实记录，无论正反。

---

## 装配爆炸图

爆炸图

`assembly-drawings/` 下共 7 张：

| 文件 | 内容 |
|---|---|
| `01_正面` `02_侧面` `03_背面` `04_四分之三` | 装配完成态，原色 |
| **`05_爆炸图_侧面`** | 15 个部件沿运动链炸开，标注名称与质量 |
| **`06_爆炸图_四分之三`** | 立体视角，可看清左右腿镜像关系 |
| `07_分色对照_装配态` | 与爆炸图同配色的装配完成态，对照用 |

## 装配结构

```
躯干主体 199g
├─ 左髋 yaw→roll 23g → 左髋 roll 6g → 左大腿 48g → 左小腿 22g → 左踝+脚 30g
├─ 颈根 37g → 颈俯仰件 6g → 头 yaw/roll 机构 49g → 头部总成+喙 189g
└─ 右髋 yaw→roll 23g → 右髋 roll 6g → 右大腿 48g → 右小腿 22g → 右踝+脚 30g

整机 737.2g   外形 144 × 141 × 264 mm
```

躯干和头几乎一样重（199g vs 189g）——**头部占整机四分之一，重心很高**，
这解释了为什么它的行走策略难训。

## 关节参数

每条腿 5 个自由度，头颈 4 个 —— **14 个受控**。
整机实际装 **15 个 Dynamixel XL330**：第 15 个驱动喙/下颚，走被动连杆，不进动作空间。

| 关节 | 行程 |
|---|---|
| `hip_yaw` | -25° ~ +30° |
| `hip_roll` | ±22° |
| `hip_pitch` / `knee` / `ankle` / `head_pitch` | ±90° |
| `neck_pitch` | -90° ~ +60° |
| `head_yaw` | ±170° |
| `head_roll` | ±25° |

## 📋 物料清单（BOM）

**要买什么、买几个** —— [`BOM.md`](BOM.md)

整机 15 个舵机、14 个轴承、约 325 件紧固件、2 块要打样的电路板，数量取自上游 MJCF 的
引用计数（38 种网格 / 75 个实例），不是估的。含每块板的器件清单与立创编号。

> ⚠️ 里面有两条会让人买错的更正：**电池是 NP-F550 不是 F970**、**XL330 被超压运行**。

## 3D 打印件与 CAD 装配体

**统一到 [fanhao375/microduck-replica-cad](https://github.com/fanhao375/microduck-replica-cad) 下载。** SolidWorks、STEP、打印工程、装配 BOM 和安装说明在同一个仓库维护。

| 版本 | 截至 2026-09-28 的 CAD 发布 |
|---|---|
| 飞特 HD-1910 | [v2.1](https://github.com/fanhao375/microduck-replica-cad/releases/tag/v2.1) |
| Dynamixel XL330 | [v1.1](https://github.com/fanhao375/microduck-replica-cad/releases/tag/v1.1) |

本仓旧 `print/` 单件和 `cad/` 装配 STL 来自上游仿真模型，未同步实物改件，现已移除；这两个目录保留下载指引。**不要把飞特和 XL330 配合件混用，也不要把本仓训练/网页网格用于打印。**

CAD 仓库的 09-15 旧 3MF 尚未包含 v2.1 合体轮胎；请核对具体附件版本，详见 [打印说明](print/README.md)。图纸与说明书由 **机械行者Robo** 建模整理，来源与许可见 CAD 仓库。

---

## 从运行时反推出的电控方案

<div align="center">
  Microduck 电控总览：板子都装在哪
  <br>
  <sub><b>五个模块的物理布局</b> —— 灰色虚线框是物理区域，实线框是模块，红色虚线框表示装在壳体<b>外面</b>。<br>
  <b>橙色</b>是舵机总线（自上而下），<b>红色</b>是电池供电（自下而上）。<br>
  最容易搞错的一条：<b>主控、HAT、摄像头三者都在头里</b>，摄像头距主控板中心约 13 mm 且中间没有关节 ——<br>
  所以 MIPI 排线不穿过脖子，真正过颈的是舵机总线和供电线。<br>
  <a href="docs/硬件入门.md">完整图集与讲解 →</a>　·　<a href="assets/hw/Microduck硬件图集.pdf">下载 PDF 图集（7 张，A3）</a></sub>
</div>

**一条 1 Mbps 的 TTL 串行总线搞定一切。**

```
                Radxa Zero 3W (RK3566) · Armbian
                  ├── UART2  1 Mbps TTL 单线半双工 ── 15× XL330 + imu_to_dxl (ID 200)
                  ├── I2C3   400 kHz (pin 3/5) ────── AIC3104@0x18 · ToF@0x29 · BMI088（未用）
                  ├── I2S3   12.288 MHz ───────────── 音频
                  ├── MIPI CSI ────────────────────── IMX219（I2C@0x10，转 90°）
                  ├── 蓝牙 ────────────────────────── 手柄 / 手机 App
                  ├── Wi-Fi ───────────────────────── WebRTC
                  └── USB-C ───────────────────────── 供电 + maskrom
```

| | |
|---|---|
| **主控** | **Radxa Zero 3W** —— 市售模块，**不是定制载板** |
| SoC | RK3566，四核 Cortex-A55，Mali-G52，0.8 TOPS NPU。官方公布 1 GB / 32 GB eMMC；复刻建议 2G/16G，见 [电控采购清单](docs/电控采购清单.md) |
| **舵机总线** | **单线半双工 TTL** —— **不是** RS-232，**也不是** RS-485。Dynamixel Protocol V2 @ 1 Mbps，走 `/dev/ttyS2` |
| **自制板 1** | **`imu_to_dxl` v2** —— 一颗会说 Dynamixel 的 LSM6DSV16X：总线 ID 200、寄存器 124，12 字节块在**同一次** `sync_read` 里和舵机一起读回 |
| **自制板 2** | **RPI Robot HAT** —— TLV320AIC3104 @ 0x18、一颗休眠的 BMI088、接 ToF 的 Stemma 座。**官方已开源**（[`elec_RPI_Robot_HAT`](https://github.com/pollen-robotics/elec_RPI_Robot_HAT)） |
| 电池 | 索尼 NP-F550，2S 锂电。**没有电量计，也没有 ADC** —— 电池电压是**读舵机上报的自身供电电压**得来的 |
| 传感器 | LSM6DSV16X IMU · VL53L5CX/L8CX 8×8 ToF · IMX219（树莓派 Camera v2） |

`imu_to_dxl` 是整套设计里最漂亮的一手：**IMU 不走 I²C**，而是把自己伪装成一个 Dynamixel 从机，
于是姿态数据和关节状态在同一次总线事务里回来 —— 不需要第二条总线，主机也不用跑姿态融合
（LSM6DSV16X 的片上 SFLP 块直接输出游戏旋转四元数，还自己估计陀螺零偏）。

**完整细节：** [硬件方案逆向](docs/硬件方案逆向.md) · [硬件规格速查](docs/硬件规格速查.md)

---

## 可行性：能造出来吗

**整机可复刻，卡点在成本不在技术。** 现状：

| 项目 | 状态 |
|---|---|
| 零件几何 | ✅ 47 个 STL |
| 装配关系 | ✅ 精确到 0.1mm，已出图 |
| 关节轴线 / 行程 | ✅ 14 个全有 |
| 质量 / 惯量 | ✅ 15 个刚体全有 |
| 舵机型号 | ✅ Dynamixel XL330 ×15 → [docs/执行器选型.md](docs/执行器选型.md) |
| 轴承 | ✅ Ø22×16×4 与 Ø15×10×3 |
| **HAT 板** | ✅ **官方 KiCad + Gerber + BOM 已开源**，直接打样 → [`elec_RPI_Robot_HAT`](https://github.com/pollen-robotics/elec_RPI_Robot_HAT) |
| **`imu_to_dxl` 板** | ⚠️ 未开源，需自绘；协议与寄存器布局已完整还原 → [docs/硬件方案逆向.md](docs/硬件方案逆向.md) |
| 主控 | ✅ **Radxa Zero 3W，市售模块**（此前误判为定制载板） |
| **紧固件清单** | ✅ 已从 STL 孔位反推 → [docs/紧固件反推.md](docs/紧固件反推.md) |
| 电池 / 传感器 | ✅ **NP-F550** 2S、IMX219、VL53L8CX、LSM6DSV16X |
| **走线方案** | ❌ 无 |
| **控制软件** | ✅ 主控用同款 Radxa Zero 3W 即可直接跑（Apache-2.0）；换主控才需移植 |
| **官方策略 ONNX** | ✅ 硬件保持同款即可直接用（9 个）；改动本体或电控才需重训 |

⚠️ **仿真 STL ≠ 可打印工程件。** 仿真只关心外形与惯量，不保证配合公差、
螺纹孔、热熔螺母座和走线空间。直接打印大概率装不起来，需要自行补充工程细节。

💰 **自己造大概率比买贵，但差多少全看渠道。** 15 个 XL330 在 ROBOTIS 国际站约 **$359**、
美国站 **$412**、欧洲含税 **€603–629** —— 也就是从「略低于整机售价」到「远超」都有可能。
加上主控、电池、两块板打样和打印耗材必然更贵。完整核价见 [BOM.md](BOM.md)。

## 现实路径

放弃 100% 复刻（`imu_to_dxl` 板与可编辑机械 CAD 未开源），改成**机械照抄 + 电控自建**：

| | 方案 |
|---|---|
| 机械 | 到 [CAD 仓库](https://github.com/fanhao375/microduck-replica-cad) 选择对应舵机版本的模型与装配说明 |
| 舵机 | XL330 × 15，市售件照买 |
| 主控 | **Radxa Zero 3W**，市售模块，与官方同款 |
| IMU 板 | 自己画 `imu_to_dxl`：LSM6DSV16X + MCU + 半双工收发器，协议已还原 |
| HAT 板 | **官方 Gerber 直接打样**（4 层板）。不要录音可整块省略，但**半双工方向电路要另配转接板**，见 [电控采购清单](docs/电控采购清单.md#六两块-pcb) |
| 软件 | 主控同款则官方 Rust 运行时可直接跑（Apache-2.0） |
| 策略 | 官方 9 个 ONNX 可用；改硬件后用 [microduck_rl](https://github.com/pollen-robotics/microduck_rl) 重训 |

**结论已从「机械可抄、电控是硬墙」修正为「整机可复刻」** ——
主控是市售模块，自制板的功能和协议已从源码完整还原。
详见 [docs/硬件方案逆向.md](docs/硬件方案逆向.md)。

---

## 三个必踩的坑

1. **Armbian 默认在 UART2 上跑登录控制台。** `serial-getty@ttyS2` 占着串口，
   必须 `systemctl mask` 掉。Pollen 是用 `fuser -v /dev/ttyS2` 查出来的。
2. **i2c3 和 FUSB302 抢引脚。** 用排针 pin 3/5 的硬件 I²C，代价是**失去 USB-C PD 协商**
   （普通 5V 充电仍然可用）。
3. **NPU 出厂是关的。** Armbian 默认禁用，要跑 RKNN 模型得刷 overlay 并重启。

---

## 生态导航

Microduck 的东西散在 GitHub 多个组织和 HuggingFace 三种资源里，**官方硬件仓库尤其容易漏**。
[`docs/生态导航.md`](docs/生态导航.md) 把官方仓库、模拟器、策略模型、数据集、社区项目
逐个标注了「是什么、能拿来干嘛」。

## 深入文档

| 文档 | 内容 |
|---|---|
| [紧固件反推](docs/紧固件反推.md)（[English](docs/fastener-reconstruction.en.md)） | 从 47 个 STL 扫描孔特征，反推出 M2 螺丝系统与采购量 |
| [执行器选型](docs/执行器选型.md)（[English](docs/actuator-selection.en.md)） | XL330 参数、BAM M6 配置、5 组标定 PD、回差建模；**为什么不能换闭环步进、换 STS3215 会怎样**（737g vs 2107g 实测对照）、**同级别舵机横向对比**（含宇树 S288 深度评估） |
| [**踩坑记录**](踩坑记录.md) | **上手前扫一遍** —— 买东西 / 打板 / 飞线 / 软件 / 工具，每条三句：现象、原因、怎么办 |
| [**调试记录**](调试记录.md) | **拿到货一步一步做** —— 舵机配 ID 改哪些参数（含 ID 对照表）、怎么供电，后面按日期记过程 |
| [**HD-1910 训练前数据清单**](docs/HD-1910训练前数据清单.md) | **给算法重训用的** —— 几何、质量惯量、关节标定、舵机规格、IMU 安装，仓库有的全填了并标出处，台架实测项列了怎么测 |
| [**不打 HAT**](docs/不打HAT.md) | **HAT 打样太贵？** ¥70 的降压模块 + 半双工转接板飞线替代，一步一步接，哪步会烧东西 |
| [**硬件入门**](docs/硬件入门.md) | **一块板一块板讲清楚** —— 五个模块各自干嘛、一个 tick 里信号怎么流、走飞特路线哪些会变，末尾附「复刻前必做的五件核对」 |
| [**硬件规格速查**](docs/硬件规格速查.md) | **一页纸规格表** —— 系统框图、芯片型号、总线参数、复刻清单、必踩的坑 |
| [硬件方案逆向](docs/硬件方案逆向.md) | 完整推导过程与证据出处（[English](docs/hardware-teardown.en.md)） |
| [**电控采购清单**](docs/电控采购清单.md) | **淘宝实链** —— 主控 / 摄像头 / ToF / 电源 / 两块 PCB / 线材与调试板，含选型推算与避坑（2026-09-04 快照） |
| [**机械采购清单**](docs/机械采购清单.md) | **淘宝实链** —— 轴承 / M2 紧固件 / 热熔螺母与压头 / 螺纹胶 / 耗材 |
| [社区动态](docs/社区动态.md) | X / GitHub 情报，含外部验证、噪音与风险提示 |

结论速览：**整机是 M2 螺丝系统**（Ø2.2 过孔 ×77 + Ø4.4 沉头孔 ×28 + Ø1.6 攻丝底孔 ×20），
结构件过孔约 146 个；轴承 Ø22×16×4 与 Ø15×10×3。

---

## 重现

```bash
# 1. 为下列装配图生成脚本拉取上游（训练工程已在 software/training/，无需此步骤）
bash scripts/fetch_upstream.sh

# 2. 重新生成装配图
python scripts/render_assembly.py upstream/microduck_rl assembly-drawings

# 3. 导出上游装配分析预览（不作为实物打印件）
python scripts/export_assembly_stl.py upstream/microduck_rl analysis-output/cad-upstream

# 4. 重新扫描孔特征
python scripts/analyze_holes.py upstream/microduck_rl/src/mjlab_microduck/robot/microduck/assets
```

依赖：`mujoco` `numpy` `pillow` `scipy`。渲染需要可用的 OpenGL 上下文。

---

## 许可证

- `scripts/` —— Apache-2.0
- `assembly-drawings/` 及保留的仿真网格 —— **CC BY-SA-NC 4.0**（上游 3D 模型为 CC BY-SA-NC，
  依 ShareAlike 条款衍生作品须沿用同协议，**不得商用**）

详见 [NOTICE.md](NOTICE.md)。本项目与 Pollen Robotics 无隶属关系，未获其背书。

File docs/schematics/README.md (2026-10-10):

# 已确认硬件原理图档案

存放**本项目实物在手、且已确认对应关系**的硬件原理图/设计源文件。每块板一个子目录，来源与版本钉死在上游提交。查证分析记录另见 `docs/references/`（那里保留研究过程，这里只放权威文件副本）。

| 子目录 | 硬件 | 确认依据 | 权威文件 | 上游来源与版本 |
|---|---|---|---|---|
| `imu-to-dxl-scrapmeta-v0.3/` | 绿色 IMU 板（imu_to_dxl v0.3，32×22mm，STM32G031F8P6 + LSM6DSV16X） | 2026-10-09 用户确认对应 [ScrapMeta/microduck-diy](https://github.com/ScrapMeta/microduck-diy/tree/main/imu_to_dxl) | `*.eprj2`（嘉立创EDA专业版工程，真源） | `main @ aa4c32d`（hardware/ 最后改动，2026-09-10）；MIT |
| `microduck-hat-v1.0-sch/` | 白色鸭图案 HAT（实物丝印 **V1.2**，2026-10-10 照片更正；Radxa Zero / Pi Zero 形态） | 2026-10-09 用户供图并确认 | `SCH_..._2026-10-06.pdf`（5 页原理图，图版本 **V1.0**） | 社区改绘版（嘉立创EDA，原理图 V1.0，2026-09-03~09-20）；派生自官方 pollen-robotics/elec_RPI_Robot_HAT（Apache-2.0）。⚠️ 图物差异大（实物多 F303 MCU + 超级电容）。查证：`docs/references/microduck-hat-20261006/` |

**没有原理图的两件到位硬件**（成品模块，无法开源存档，只留定位信息）：

| 硬件 | 说明 |
|---|---|
| 微雪 Waveshare Bus Servo Adapter (A) | 商品模块，USB/UART 转半双工总线舵机；官方产品页有规格书（waveshare.com），需要时下载存档 |
| 黑色降压模块（XT60，丝印 7.2-16V） | 通用商品模块，无公开原理图；用前实测输入下限/输出（见 PROGRESS 待办） |

> 同源参考：fanhao375 replica 的 imu_to_dxl 原理图 PDF（STM32G031 同引脚布局的另一块板）在参考库 `microduck-replica/hardware/imu_to_dxl/imu_to_dxl-原理图.pdf`，可作对照，但**不是本档案板的图**。

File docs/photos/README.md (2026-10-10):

# 硬件照片存档

用户实拍照片的统一存放点。微信缓存目录（`Documents/WXWork/.../Cache/Image/`）会被清理，收到即拷贝到这里永久保存。**到货新照片一律往这里加，并在下方登记表补一行。**

## 登记表

| 文件 | 拍摄对象 | 收到日期 | 一句话说明 | 关联待办 |
|---|---|---|---|---|
| [multimeter-delixi-6000counts.jpg](./multimeter-delixi-6000counts.jpg) | 万用表（德力西） | 2026-10-09 | 6000 位手动量程数字万用表，本项目的电测工具 | 降压模块实测、banana_pcb 核极性 |
| [dc-power-supply-delixi-dlx-30v10amf.jpg](./dc-power-supply-delixi-dlx-30v10amf.jpg) | 直流稳压电源（德力西） | 2026-10-10 | DLX-30V10AMF 可调电源，30V/10A 上限 | 降压模块输入下限扫描、首次上电限流保护 |
| [buck-module-xt60.jpg](./buck-module-xt60.jpg) | 黑色降压模块原件 | 2026-10-10 | XT60 输入、选压焊盘 5/6/7V（无电位器） | 输入下限扫描、输出档位确认 |
| [buck-module-xt60-annotated.jpg](./buck-module-xt60-annotated.jpg) | ↑ 的元件标注版 | 2026-10-10 | v2（实测后勘误）：10 处元件编号 + 图例，⑧=3P 排针⑨=PWR OUT 红塑 2P；脚本 `scripts/annotate_buck_module.py` | 对照实物讲解/测试接线 |
| [buck-module-xt60-back.jpg](./buck-module-xt60-back.jpg) | 降压模块背面 | 2026-10-10 | 板名 BUS SERVO POWER SUPPLY V1.3（By 造物の乐趣），背面有 VOLT_SEL 选压焊盘/排针焊点/二维码 | 确认板子身份与接口定义 |
| [buck-module-xt60-back-annotated.jpg](./buck-module-xt60-back-annotated.jpg) | ↑ 的接口标注版 | 2026-10-10 | v4（勘误无 DC 母座）：① 金色圆孔（疑安装孔）② 二维码 ③ XT60 焊点 ④ VOLT_SEL 焊盘（改焊处）⑤ PWR OUT 焊点 ⑥ 3P 排针焊点 ⑦ 安装孔 | 实测/改焊时对照 |
| [waveshare-bus-servo-adapter-a.jpg](./waveshare-bus-servo-adapter-a.jpg) | 微雪总线转接板正面 | 2026-10-10 | Bus Servo Adapter (A) v1.1，双舵机口 + UART 排针 + USB-C + DC 母座/端子 | 台架总线调试接线对照 |
| [waveshare-bus-servo-adapter-a-annotated.jpg](./waveshare-bus-servo-adapter-a-annotated.jpg) | ↑ 的元件标注版 | 2026-10-10 | 7 处标注 + 用法要点；脚本 `scripts/annotate-waveshare-adapter.py` | 台架接线/模式跳线对照 |
| [hat-v1.2-front.jpg](./hat-v1.2-front.jpg) | HAT 正面 | 2026-10-10 | 实物丝印 **V1.2**（此前档案误记 V1.1）；舵机口×2、Qwiic×4、扬声器/麦克风座群、超级电容 | 图物差异核对 |
| [hat-v1.2-back.jpg](./hat-v1.2-back.jpg) | HAT 背面 | 2026-10-10 | **F303 类 MCU（V1.0 原理图无此件）**、PAM8406、40P 排母、圆形焊盘×8 | 索取 V1.2 原理图 |
| [hat-v1.2-front-annotated.jpg](./hat-v1.2-front-annotated.jpg) | ↑ 正面标注版 | 2026-10-10 | 8 处标注；脚本 `scripts/annotate-hat.py` | 接线对照 |
| [hat-v1.2-back-annotated.jpg](./hat-v1.2-back-annotated.jpg) | ↑ 背面标注版 | 2026-10-10 | 7 处标注 + 关键发现 | 接线对照 |

## 降压模块（黑色，XT60 输入）— 2026-10-10 照片识别（正面+背面）

正反面共三次视觉识别 + 像素色块校验（红端子质心与标记完全吻合）。**照片识别、实物未复测**，丝印文字以手上实物为准。

**板子身份（背面丝印）**：**BUS SERVO POWER SUPPLY V1.3**，By **造物の乐趣**（@Make & Share），带二维码（微信压缩图码点损坏，OpenCV 无法解码，**待手机扫描取作者文档**）。网检（2026-10-10）：本地三个参考库与公开网络均无此板资料——社区文章[证实电源板是 microduck 复刻需自研的关键件](https://post.m.smzdm.com/p/a70nxnqg)，此板应为某位社区作者的自研件。丝印 **OUT PWR: 5V or 7.4V MAX 6A**——"5V 或 7.4V"疑似"稳压 5V / 直通电池 7.4V"两种输出模式，待二维码文档或实测确认。

**正面元件（编号对应标注图）：**

| # | 元件 | 识别要点 |
|---|---|---|
| 1 | XT60 输入插座（母头） | Amass，丝印 PWR IN 7.2-18V +/− |
| 2 | 选压焊盘 7V/6V/5V（VOLT_SEL） | 三对焊盘焊锡桥选定输出电压，**当前桥哪档照片不可辨** |
| 3 | 功率电感 | 屏蔽方型，丝印 4R7 = 4.7µH |
| 4 | 降压主控 IC | SOIC 无散热罩，旁有 MAX: 6A 丝印，型号待实物近拍 |
| 5 | 贴片功率器件区 | MOSFET/二极管/电阻小件 |
| 6 | 输入电解电容 ×2 | 丝印 22 16V |
| 7 | 输出电解电容 | 丝印 100µF 16V（CK） |
| 8 | 3P 输出排针（白座） | 丝印 GND/VCC/NC，实测 VCC=6.00V 稳压输出 |
| 9 | PWR OUT 输出端子（红塑 2P） | 实测跟随输入=电池直通，舵机总线走它 |
| 10 | 安装孔 ×4 | 四角 |

**背面另见**：金色圆孔一颗（**2026-10-10 勘误：曾据照片误判为 DC 母座，用户实物核对板上无此件**，疑为镀铜安装孔/过孔，实物待认）、VOLT_SEL 选压焊盘（改焊处）、XT60 大焊点 ×2、3P 排针焊点（左边缘竖排）。

**关键风险（同前）**：输入丝印 7.2-18V，2S 带载跌 6.6V 可能掉出稳压；IMU 板 LDO 上限 5.5V，若选压焊盘桥在 6V/7V 档接 IMU 会烧。

**实测手顺（2026-10-10 已完成空载扫描，结论见 [buck-module-test.md](../buck-module-test.md)）：** 剩余：台架带载复测。~~核 DC 母座~~（勘误：板上无此件）。~~改焊 5V 档~~（2026-10-10 v2 评审取消：AP2210K-3.3 输入上限实为 13.2V，IMU 直挂总线，本板稳压支路无负载）。**该板在整机中的角色与接线见 [power-architecture-v2.md](../power-architecture-v2.md)（历史版本 v1 同目录存档）。**

## 微雪总线转接板 — Bus Servo Adapter (A) v1.1 — 2026-10-10 照片识别

板子身份（左缘竖排丝印）：**Bus Servo Adapter (A) v1.1**，Waveshare，板 42×33mm、安装孔 φ2.5×4（孔距 37×28mm）。成品模块无公开原理图；规格以[微雪官方 wiki](https://www.waveshare.com/wiki/Bus_Servo_Adapter_(A)) 为准。**照片识别、实物未复测**；板载降压 IC 与 USB 串口芯片型号丝印照片上不可辨（USB 串口按微雪资料为 CH343）。

**正面元件（对应标注图 [waveshare-bus-servo-adapter-a-annotated.jpg](./waveshare-bus-servo-adapter-a-annotated.jpg)）：**

| 元件 | 识别要点 |
|---|---|
| 舵机口 ×2（白座 5264-3P） | 丝印 D/V/G = 数据/电源/地；两口并联，菊链最多 253 颗 |
| UART 排针 TX/RX/GND | A 模式接 MCU；微雪 wiki 提醒 **RX-RX、TX-TX 直连**（丝印已按对端标注，勿交叉） |
| 模式跳线帽 ×2（黄色） | **A = UART 控制 / B = USB 控制**，对照板面 A/B 表格丝印 |
| USB-C 座 | B 模式接电脑（CH343 串口，微雪总线工具/LeRobot 可用） |
| DC 母座 5.5/2.1 ∥ DC+/DC- 螺丝端子（绿 2P） | 电源输入，两路并联；丝印 DC 9-12.6V |
| 板载降压（SOIC-8 + 47µH 电感） | 仅供板内逻辑；**不给舵机稳压** |
| PWR 电源指示灯 | 右下角 |
| 半双工转换与阻容区 | UART↔单线总线收发切换电路（芯片丝印未读清） |

**关键事实（官方资料 + 第三方实测一致）**：**输入电压直通舵机口 V 脚，板上不给舵机稳压**——输入必须等于舵机额定电压。丝印 9-12.6V 是针对 ST 系 12V 舵机的标称；微雪 wiki 注明 5-8.4V 亦可输入。

**本项目用法**：HD-1910 是 7.4V 舵机 → 台架喂 **2S（6.6-8.4V）正确，严禁 12V**。角色 = 台架总线调试（舵机改 ID/零位、imu200 验收、对比飞线/FE-URT-2 方案），**不进整机供电链**（整机架构见 [power-architecture-v2.md](../power-architecture-v2.md)）。

## HAT — Microduck Controller Hat for Radxa Zero 3W（实物 V1.2）— 2026-10-10 照片识别

板子身份（正面丝印）：**Microduck Controller Hat for Radxa Zero 3W**，实物版本丝印 **V1.2**（正背面均有）。**⚠️ 此前档案记为 V1.1，以实物为准更正为 V1.2**；存档原理图（[SCH PDF](../references/microduck-hat-20261006/SCH_Microduck-Hat-for-Radxa-Zero_2026-10-06.pdf)）仅为 **V1.0**。照片识别、未上电未复测。

**关键发现（图物差异）**：

1. **背面有一颗 F303 类 MCU**（LQFP48，丝印 ?32F303CET6，品牌前缀不可辨）+ 金属壳晶振——V1.0 原理图 5 页中**没有任何 MCU**，属 V1.1/V1.2 新增，用途未知（总线卸载/电源管理/RTC 皆有可能）。
2. **正面有一颗超级电容**（丝印疑 1.0F 5.5V）——V1.0 图中无，疑为 MCU 的 RTC 备份电源。
3. 背面中部有**圆形焊盘 ×8**（两排各 3 金 + 1 银）——疑电源/总线输入焊盘，待核。
4. RS485 座（EH 4P ×2）位置为**空焊盘未焊**；本项目用 TTL 总线，不影响。

**正面元件（对应 [hat-v1.2-front-annotated.jpg](./hat-v1.2-front-annotated.jpg)）：**

| 元件 | 识别要点 |
|---|---|
| 舵机口 ×2（JST EH 3P，左缘大白座） | 丝印 SERVOS；按 V1.0 图：1=GND 2=+BATT 直通 3=DATA（V1.2 待复核） |
| Qwiic/I2C 座 ×4（SH 1.0 4P） | 丝印 I2C3 / I2C4 / I2C5 等 |
| RS485 座焊盘 ×2（EH 4P） | 空焊盘未焊 |
| AP63205 5V 降压区 | 电感丝印 CK 6R8 = 6.8µH，与 V1.0 图 L1 一致 |
| 超级电容 | 丝印疑 1.0F 5.5V，V1.0 图无，待核 |
| 扬声器/麦克风座群 | 丝印 SPEAKERS、LEFT/RIGHT、Mic、MICS |
| 40P 排母焊盘（正面） | 排母本体焊在背面，插 Radxa Zero 3W |

**背面元件（对应 [hat-v1.2-back-annotated.jpg](./hat-v1.2-back-annotated.jpg)）：**

| 元件 | 识别要点 |
|---|---|
| F303 类 MCU（LQFP48） | 丝印 ?32F303CET6；**V1.0 图无此件** |
| MCU 晶振 | 金属壳贴片 |
| PAM8406 音频功放（SOP-16） | 与 V1.0 图 U12 一致 |
| 40P 排母 | 2×20，插 Radxa Zero 3W |
| 小信号芯片区 | SOT-23-5/6 多颗（LDO/74LVC/LM5050 等，待 V1.2 图对照） |
| 圆形焊盘 ×8 | 疑电源/总线输入，待核 |

**行动项**：接线/上电前向板卡来源索取 **V1.2 原理图或改动说明**（重点：MCU 功能与固件、+BATT 入口形式、舵机口供电路径是否与 V1.0 一致）。供电架构分析（[power-architecture-v2.md](../power-architecture-v2.md)）基于 V1.0 图，舵机口 +BATT 直通等结论需按 V1.2 实物复核。

## 万用表 — 德力西 6000 位数字万用表

6000 Counts（最多显示 5999），手动量程。照片状态：显示 `000 mV` + DC，直流毫伏档空载。

**档位（旋钮）**

- `V⎓` 直流电压 ×4 档：600m / 6 / 60 / 600（V）。测 3.3V/5V 用 6V 档，7.4V 电池及以上用 60V 档
- `V~` 交流电压：600V~（配 Live 火线识别档）
- `Ω` 电阻 ×5 档：600 / 6k / 60k / 600k / 6M（断电测量）
- 蜂鸣/二极管档：响=通；二极管正向约 0.5~0.7V
- `A⎓` 直流电流：60μ / 600μ / 6m / 60m / 600m（红笔在 VΩmA 孔）+ 10A 专用档（红笔换 10A 孔）
- `NCV` 非接触验电、`OFF` 关机

**插孔**

- `COM`：黑表笔，公共端，任何测量都在这
- `VΩmA`：红表笔，测电压/电阻/通断/≤600mA 电流；内部 **600mA 保险丝**
- `10ADC`：仅 10A 档用，**无保险丝（UNFUSED）**，超 10A 直接烧表

**按钮**：左=背光，右=HOLD 读数锁定。

**红线**：禁止带电测电阻；禁止电流档测电压；测完电流红笔立刻插回 VΩmA。

## 直流稳压电源 — 德力西 DLX-30V10AMF

可调线性/开关直流电源，最大 **30V / 10A**。照片状态：3.00V、0A、C.V. 灯亮（恒压、空载）。

**面板**

- `VOLTAGE` 旋钮（带 SETOUT）：调输出电压
- `CURRENT` 旋钮（带 LOCK）：调**电流上限**（限流保护值，不是输出电流）
- `ON/OFF` 按键：输出通断（按键灯亮=输出开）
- 三行显示：绿=电压 V，红=电流 A，黄=功率 W
- `C.V.` 灯=恒压正常工作；电流顶到上限时跳 `C.C.`（恒流，电压自动压下来，起保护作用）

**本项目用法**

1. 降压模块实测（PROGRESS 待办）：电源接模块输入，万用表并输出，电压 12V→6V 扫描找掉出稳压点，判定 2S 电池（带载跌 6.6V）是否可用
2. 电路板首次上电：先限流 0.1~0.2A 排短路，正常后放宽到 0.5~1A
3. 电机单独测试可直接带，但与开发板同测时分两路供电、GND 共地，不共用同一路 5V

## 新增照片规则

- 文件名：`主题-型号.jpg`（英文小写连字符），收到日期写登记表
- 待收照片（拍后补入）：IMU 板 J2 焊盘面、舵机清点、打印件清点、降压模块主控 IC 近拍；**二维码用手机扫（结果发给助手即可），压缩照片解不了码**
- 说明写在对应小节，重点记"照片里当时的状态"和"后续要用它核对什么"

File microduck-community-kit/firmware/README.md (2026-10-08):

# "imu_to_dxl" 板子对应的固件

硬件在：hardware/imu_to_dxl

GD库使用的版本是GD32F30x_Firmware_Library_V3.0.3

目前烧录使用的JLink版本是JLink_Linux_V696_x86_64

## 其他说明
 - 固件由AI编写

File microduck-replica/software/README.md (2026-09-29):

# software · 软件适配

> 本目录保留训练所需的上游仿真模型，**不是最新实物结构件的打印来源**。模型下载统一到 [microduck-replica-cad](https://github.com/fanhao375/microduck-replica-cad)；引入飞特舵机参数不等于已更新 CAD 几何、质量和惯量。

官方运行时 [`pollen-robotics/microduck`](https://github.com/pollen-robotics/microduck) 是照 Dynamixel XL330 写的，本仓库主线用飞特 HD-1910，软件要改。这个目录放**训练工程、分析和方案**；Rust 运行时适配代码仍在下方所列的 fork 分支里。

## HD1910 仿真训练

**[`training/`](training/)** 包含完整 Python 训练工程：模型、LuwuDynamics 的 1910 M6 参数、
HD1910 任务配置、飞特控制器初始化适配、依赖锁文件和测试。克隆本仓库即可取得，
不需要再下载 `microduck_rl` 分支。

[快速开始](training/README.md) · [运行说明与初始化问题解释](training/docs/hd1910-baseline.md) ·
[来源和许可证](training/UPSTREAM.md)。当前是仿真接入基线，尚未完成本机实测步态训练。

## IMU 裸板调试

STM32G031 + LSM6DSV16X 固件与硬件资料放在 [`hardware/imu_to_dxl/firmware/`](../hardware/imu_to_dxl/firmware/)。姿态显示并入 [`tools/servo-web/`](../tools/servo-web/)：使用 `python server.py --port COM5 --imu-jlink imu-jlink.json`，同一个模型同时接收舵机关节角和 J-Link 的躯干姿态；只有裸板时可用 `--fake` 代替串口参数。

**范围：SWD 台架观察。** 附带固件仍是 Dynamixel Protocol 2.0 基线，尚未实现飞特地址 56、15 字节契约，不能据此宣布飞特 IMU 总线或整机验收通过。

## Rust 运行时代码在哪

> ### 👉 [`fanhao375/microduck` · `feetech` 分支](https://github.com/fanhao375/microduck/tree/feetech)
>
> 已跟上官方 **0.14.1**，三个 crate 的测试全过（duck-control 80 / robotd-params 151 / robotd 93）。**还没上过板**，等零位校准。

| 文件 | 行数 | 做了什么 |
|---|---|---|
| [`duck-control/src/bus_feetech.rs`](https://github.com/fanhao375/microduck/blob/feetech/duck-control/src/bus_feetech.rs) | 744（新） | **`FeetechIo` 主体**：每 tick 一次 `sync_read` 地址 56 长 15；位置换算带方向表；写目标带钳位；`set_gain` 只写 P（飞特没有 I/D 同构）；`reboot` 先关扭矩再 0x08；开机检查 END 字节序 / 应答级别 / 运行模式 / 波特率 / 相位；`imu_ready()` 恒 false。含 11 个单元测试 |
| [`duck-control/src/bus_select.rs`](https://github.com/fanhao375/microduck/blob/feetech/duck-control/src/bus_select.rs) | 149（新） | `AnyBus` 枚举，两种后端二选一（`Box<dyn RobotIo>` 编不过，原因见[架构文档](飞特适配架构.md) §3.1） |
| `robotd-params/` | +50 | `[bus] protocol = "dynamixel2" \| "feetech-sts"`、`[bus.feetech] p_scale / directions`，登记进参数表 |
| `robotd/src/main.rs` | +63 | `BusIo` 换成 `AnyBus`，开总线时带协议；参数不合法直接报错不重试 |
| `duck-control/src/model.rs` | +8 | HD-1910 出厂运行模式 4 的期望值 |
| `deploy/robotd.toml` | — | 两个新键，带注释 |

编译（需要 Rust）：

```bash
git clone -b feetech https://github.com/fanhao375/microduck.git
cd microduck && cargo test -p duck-control -p robotd-params -p robotd
```

**为什么放 fork 不放这个仓库**：`FeetechIo` 是官方 Rust 工作区里 `duck-control` 这个 crate 的一个文件，
用的是官方的 `RobotIo` trait、`Safety<T>` 泛型和参数系统 —— 单独拷出来编译不了。
放在 fork 分支上，官方更新时 `git rebase` 就能跟上（2026-09-20 跟了 55 个提交，零冲突），
将来也能直接向官方提 PR。官方是 Apache-2.0，改动留在 fork 里出处也清楚。

| 文件 | 内容 |
|---|---|
| [`飞特适配架构.md`](飞特适配架构.md) | 官方运行时现有架构（接缝在哪、每个 tick 干什么、开机序列）、两家舵机逐项差别、适配方案、**`imu_to_dxl` 小板固件架构（§4）**、台架验收、待查清单、构建部署 / 策略关系 / 失败模式、评审记录 |

小板固件的接口契约（15 字节块、时序、排队规则、验收）单独成文：[`hardware/imu_to_dxl/总线协议.md`](../hardware/imu_to_dxl/总线协议.md)，配套工具 [`tools/imu200/`](../tools/imu200/)（假小板 + 测试向量 + 真板子验收）。

板子怎么烧、怎么装官方运行时，在 [不打 HAT](../docs/不打HAT.md) 和 [`tools/radxa/`](../tools/radxa/)。

飞特协议和内存表的官方原文（2026 年版快照）在 [`docs/飞特资料/`](../docs/飞特资料/)。

动代码前先把舵机点通：[`tools/servo-web/`](../tools/servo-web/) 是接串口的网页调试台，拖滑块、看回读、导寄存器底账、3D 鸭子跟着动，架构文档台架清单 0–8 项都用它。

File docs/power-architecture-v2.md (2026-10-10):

# 整机供电架构 v2（飞特路线，2026-10-10 修订）

> 本文取代同日定稿的 [power-architecture-v1.md](./power-architecture-v1.md)。v1 保留作历史记录，不要删。

## 为何从 v1 改到 v2（改动说明）

v1 有两处事实错误，2026-10-10 评审时用器件手册与 HAT 原理图渲染图证伪：

### 错误 1：「IMU 板 LDO 上限 5.5V，插总线即烧」不成立

IMU 板 U3 是 **AP2210K-3.3**，数据手册最大输入 **13.2V**（Farnell / RS 参数页一致），2S 满电 8.4V 远在规格内。佐证设计意图的细节：

- 板子输入电容 C5 是 10µF/**50V**（[hardware-netlist.md](./schematics/imu-to-dxl-scrapmeta-v0.3/hardware-netlist.md)）——只吃 5V 的设计不会选 50V；
- 官方 HAT 的 Dynamixel 接口直出电池原电压，板上唯一的 5V 降压只给主控（replica BOM 核对结论）；
- replica 自绘 IMU 板专为 8.4V 总线选 30V 宽压 LDO（HT7533-1）+ 12V TVS + 25V 输入电容，输入电容直接挂总线；
- community-kit 的 IMU 成品板直挂 dxl_hub 电池总线，真机 15×HD-1910 + 50Hz 环路验证过；
- 热耗核算：8.4→3.3V × 约 15mA ≈ 77mW，SOT-23-5 温升十几度。

**后果**：v1 的「混血 3P 线」铁律与「改焊 5V 档 + 空载复验」任务都不是必须的——IMU 可以像舵机一样直挂总线。混血线还引入一个 v1 没看到的隐患：总线有电而 5V 支路断电时，数据线会经 R6 往未上电的 IMU 板灌电流。直挂则电与数据同源同插，不存在这个状态。

### 错误 2：「HAT 舵机口 +BATT 经 F1 自恢复保险 + 5.1V TVS」不成立

渲染 HAT 原理图第 4 页逐网络核对（渲染图存 [page4.png](./references/microduck-hat-20261006/page4.png)，源文件为同目录 5 页 PDF）：

- **F1（PRG18BB101MB1RB）串在数据线 pin 3 上**，D3（BZT52C5V1S）是数据线 5.1V 钳位；
- 舵机口 pin 2 的 **+BATT 完全直通，无任何保险**；
- F1 保持电流仅 **21mA**（跳闸 45mA，Murata 手册），是信号线保护器件，物理上不可能过舵机电流。

**后果**：v1 未定项「总线电流过不过 F1 保险」关闭——总线电流本来就不经过它。同时浮出 v1 没写的真风险：**整机电源链没有保险丝**（见风险节）。

### v1 中维持不变的结论

电源板空载实测数据（6V 档、稳压下限 ≈6.3V、PWR OUT 直通）、HAT 板内 AP63205 5V/2A 只供主控、舵机吃电池直通电压、舵机口针序 1=GND / 2=+BATT / 3=DATA 与 IMU 板 J1 同序、电源板丝印 MAX 6A 天花板、HAT 原理图 V1.0 与实物 V1.2 差异待确认。

## 一句话结论

**电池直通是唯一的动力母线：舵机、HAT、IMU 全部吃电池原电压；5V 只存在于 HAT 板内（给主控）。降压模块退化为可选的转接件。**

## 拓扑

```
NP-F550 2S 电池（8.4V 满 → 带载最低 6.6V）
  │
banana_pcb（U6068 插针 ×2 + 焊接出线，线径按 3-5A）
  │   ⚠️ 建议在此串 5A 保险丝（全链目前无保险，见风险节）
  ▼
[可选] BUS SERVO POWER SUPPLY V1.3 —— 纯转接：XT60 进 → PWR OUT 直通出
  │      （VCC 稳压口闲置，当前 6V 档不用动；拿掉它则自制线直连 HAT）
  ▼
HAT 的 +BATT 电源口
  ├─ 板内 AP63205 降 5V/2A ──→ 主控 Radxa Zero 3W
  └─ 舵机口 CN11/CN12（JST EH 3P）直出 +BATT（无保险）
       ├─→ 舵机总线链：HD-1910 ×15（电池电压，真机用法 7.8-8.1V）
       └─→ IMU 板 J1（直挂总线，板内 AP2210K-3.3 自降 3.3V）
```

建议总线**分两支**挂 CN11、CN12（如左右腿各一口）：JST EH 座额定 3A，单链 15 颗会让首座过全链电流（社区实测整机常态 3-5A）。

## 各板取电方式

| 板 | 电从哪来 | 接口与备注 |
|---|---|---|
| banana_pcb | 电池触点 | U6068 插针 ×2 + 拆电池焊接出线；线径 3-5A；建议串 5A 保险 |
| 电源板（可选） | banana_pcb 出线 | 仅作 XT60→螺丝端子转接；VCC 稳压口闲置，6V 档保持不动 |
| HAT | 电池直通（电源板 PWR OUT 或直连） | 板内 AP63205 降 5V/2A，**只够主控**；舵机口直通无保险 |
| 主控 Radxa | HAT 板载 5V | 经 HAT 板载供电，无需自行接线 |
| 舵机 ×15 | 总线电池电压 | 分两支挂 CN11/CN12；EH 3P vs 飞特原线 5264 端子，装前试插 |
| IMU 板 | **总线电池电压**（J1 pin2） | 板内 AP2210K-3.3（耐 13.2V）自降 3.3V；上电前台架验证一次 |

## IMU 板接线（取代 v1 三铁律）

J1 = JST EH 3P，引脚 **1=GND、2=VBATT、3=DATA**，与 HAT 舵机座同序。

1. IMU 是**普通总线节点**：J1 直插 HAT 第二舵机口或链上任一空座。叶节点 J3 空着即可；J1/J3 板内并联，需要时也可继续串。
2. 数据电平两侧均为 3.3V（HAT 的 74LVC 驱动由 +3V3 供电，见原理图第 4 页），IMU 板的 D1/D2 与 HAT 的 D3 钳位正常工况都不动作。
3. **上电前一次性台架验证**（覆盖「实物 LDO 与设计文件不符」的残余风险，替代 v1 的改焊复验）：台架电源限流 0.1A，从 J1-2 给 IMU 板升压至 8.4V，确认 J2-1 的 +3V3 轨稳定 3.3V、U3 不烫。通过即闭环。
4. J2 调试口 pin1（+3V3）仍是板内 3.3V 轨引出，**不是供电入口**；烧录时仅作 DAPLink 电平参考（此条与 v1 一致）。

## 未定项与风险

- **全链无保险丝**：banana_pcb 纯直通、电源板 PWR OUT 直通、HAT 舵机口直通，从电池到舵机无过流保护，只靠 NP-F550 电池自带保护板兜底。建议 banana_pcb 出线串 5A 保险丝（fanduck 触点板即预留保险位，同思路）。
- **EH 座载流**：额定 3A vs 整机常态 3-5A，分两支挂口；真实电流台架带载复测量。
- 电源板丝印 **MAX 6A** 天花板不变；15 颗同时堵转远超此数，靠 robotd 飞特补丁力矩限幅兜底（真机整定值待复测）。
- HAT 原理图 V1.0 vs 实物 PCB V1.2 差异仍未确认（接线前向板卡来源索取 V1.2 图纸或改动说明，v1 已记）。
- HAT 供电链细节：LM5050 理想二极管在 buck 之后的 +5V 轨（OR-ing/防倒灌），PWR_DET 关机检测在 +BATT 上分压——与本架构无碍，详见 HAT 查证记录与原理图第 2 页（渲染图 [page2.png](./references/microduck-hat-20261006/page2.png)）。

## 版本历史

- **v1**（2026-10-10）：首版定稿，基于电源板空载实测 + IMU 网表 + HAT 文本提取。两处事实错误见本文开头，原文存档 [power-architecture-v1.md](./power-architecture-v1.md)。
- **v2**（2026-10-10）：评审修订。IMU 改直挂总线、电源板降为可选转接件、关闭 F1 未定项、新增「全链无保险」与「EH 座分流」两个风险项、以台架 8.4V 验证取代改焊 5V 任务。

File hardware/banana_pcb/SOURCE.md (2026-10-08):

# banana PCB 来源与打开说明

- 来源：[jyg9/microduck-community-kit](https://github.com/jyg9/microduck-community-kit/tree/0a73426c084ae5a94cdedf5d2be0e3ff5134334d/hardware/banana_pcb)。
- 固定提交：0a73426c084ae5a94cdedf5d2be0e3ff5134334d。
- 下载日期：2026-10-08（Asia/Shanghai）。
- 原目录全部 7 个文件原样保留，包括 KiCad 工程、原理图、PCB、Gerber 制造包、说明、图片和硬件许可证。
- 每个下载文件已按 GitHub 的 Git blob SHA-1 和字节数核验；SHA-256 记录见 source-manifest.json。
- 硬件许可证见 LICENCE.txt；仓库根 LICENSE 另存为 UPSTREAM-REPOSITORY-LICENSE.txt。不同范围的许可不得混同。

## 打开

使用 KiCad 打开 banana_pcb.kicad_pro；双击工程中的 banana_pcb.kicad_pcb 进入 PCB 编辑器。
原工程由 KiCad 9 创建。本机安装 KiCad 10.0.7；保存可能升级文件格式，编辑前建议另存副本。
本次下载与打开不修改原设计，不代表通过 DRC、生产审查或实物适配验证。

## 使用边界

这是社区电池取电转接板，不是已确认的 Pollen 官方原版。与本项目既有 A/B 方案独立保存，不自动并入任何方案。
接线前须核对实物极性、插针间距、绝缘与载流能力；该板本身不提供降压、充电或保险保护。

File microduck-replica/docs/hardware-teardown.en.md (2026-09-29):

# Microduck Electronics, Reverse-Engineered

> ⚠️ **This English version lags behind the Chinese original.** Several corrections (camera rotation, MK1 part number, U10 placement, STS3032 torque basis, board SKU) were applied to the Chinese docs first. **When the two disagree, the Chinese version wins.** Last sync: 2026-09-05.

[简体中文](硬件方案逆向.md) · **English**

**Method:** the Rust runtime is open source, and a runtime that drives real hardware has
to hard-code device paths, I²C addresses, register offsets, baud rates and protocols.
**The code is the datasheet.** Everything below comes from the source, device trees and
config files in the `pollen-robotics/microduck` repository.

---

## 1. System Overview

```
                    ┌──────────────────────────────┐
                    │   Radxa Zero 3W (RK3566)     │  65 × 30 mm
                    │   Armbian / kernel 6.1.115   │  Pi Zero form factor
                    └──┬────────┬─────────┬────────┘
          /dev/ttyS2   │        │ 40-pin  │ MIPI CSI
          1 Mbps UART  │        │         │
        ┌──────────────┘        │         └── IMX219 camera (mounted upside down)
        │                       │
        │              ┌────────▼─────────────────┐
        │              │  Pollen RPI Robot HAT    │  65×30mm custom (published)
        │              │  i2c3 @ 400 kHz          │
        │              │   ├ TLV320AIC3104  0x18  │  audio codec
        │              │   ├ BMI088   0x19/0x68   │  fitted but unused
        │              │   └ Stemma J5 → ToF 0x29 │
        │              │  battery feeds the robot │
        │              │  through this board      │
        │              └──────────────────────────┘
        │
   ═════╪═══════════ Dynamixel bus (Protocol V2, 1 Mbps) ═══════════
        │
        ├── 15 × Dynamixel XL330   IDs: L leg 20-24 / neck-head-mouth 30-34 / R leg 10-14
        └── imu_to_dxl v2 board    ID: 200      ← the second custom board
              └ LSM6DSV16X
```

**The central design idea: one Dynamixel bus does everything.** The IMU is not on I²C —
it is built as a Dynamixel slave sitting on the servo bus, and is read in the **same
`sync_read` transaction** as the servos. Pack voltage needs no fuel gauge either: the
firmware simply reads what the servos report as their own supply.

---

## 2. Main Board: Radxa Zero 3W

| Item | Value | Evidence |
|---|---|---|
| SoC | **RK3566** | `compatible = "radxa,zero-3w", "rockchip,rk3566"` |
| Form factor | Pi Zero, 65×30 mm, 40-pin header | matches the size of `pcb__raspberry_pi_zero_2_w.stl` |
| OS | **Armbian** (Debian-based), vendor kernel 6.1.115 | `armbianEnv.txt`, overlay comments |
| Servo serial port | **`/dev/ttyS2`** | `deploy/robotd.toml` |
| NPU | **0.8 TOPS / INT8 / single core**, node `npu@fde40000`, **disabled by default in Armbian** | `npu-bringup.md`; overlay + `setup-npu.sh` + reboot, see [§7b](#7b-the-npu-and-on-board-vision) |
| Policy inference | ONNX Runtime ≥1.23 (installs 1.28.0), loaded with `dlopen` | `Cargo.toml` workspace metadata |
| NPU inference | rknn-toolkit2 runtime | same |

> 💡 **The single most important finding:** the main board is not a custom carrier.
> It is an **off-the-shelf Radxa Zero 3W**. An earlier version of this document claimed
> "the RK3566 carrier is custom and unobtainable" — that was wrong. It is a stock module.

---

## 3. `imu_to_dxl` v2 — the one board you must build

**The most elegant piece of the design, and the easiest one to reproduce.**

| Item | Value |
|---|---|
| IMU chip | **LSM6DSV16X** (ST 6-axis, with the SFLP on-chip sensor-fusion block) |
| Interface | **Dynamixel bus** — *not* I²C |
| Bus ID | **200** |
| Register address | **124** |
| Read by control loop | 12 bytes |
| Full diagnostic block | 20 bytes (also raw accelerometer, sample counter, status flags) |

### The 12-byte block

| Bytes | Contents |
|---|---|
| `0..6` | gyro x/y/z, `i16` little-endian raw counts, range **±500 dps**, **17.5 mdps/LSB** |
| `6..12` | SFLP quaternion x/y/z as **IEEE half-precision (fp16)**; `w = √(1 − x² − y² − z²)` |

### Why it is built this way

1. **No extra bus** — it comes back in the same `sync_read` as the 15 servos, at zero
   additional cost.
2. **No host-side fusion** — the LSM6DSV16X's SFLP block emits a game-rotation quaternion
   on-chip and estimates its own gyro bias.
3. **Only three quaternion components are sent** — a unit quaternion lets `w` be
   reconstructed, saving a byte pair so the whole thing fits in one transaction.

### What it takes to build one

- LSM6DSV16X (or a pin-compatible ST 6-axis part)
- A small MCU acting as a Dynamixel Protocol V2 slave (an STM32G0 or CH32V is plenty)
- A half-duplex TTL transceiver (the Dynamixel bus is single-wire half-duplex)
- Power taken from the bus

**This is the board most worth designing yourself in the whole project** — few components,
clear logic, and the protocol is fully documented above.

---

## 4. Pollen RPI Robot HAT — **already published; do not redraw it**

> 📌 **Correction (2026-09-03)**: this section previously treated the board as unpublished and
> in need of reverse engineering. **That was wrong.** The board is fully open at
> [`pollen-robotics/elec_RPI_Robot_HAT`](https://github.com/pollen-robotics/elec_RPI_Robot_HAT)
> (**Apache-2.0**): KiCad 9 schematic and PCB, Gerbers, BOM, pick-and-place, STEP, plus every
> datasheet. The earlier search covered only the `microduck` repository and missed the
> organisation's `elec_`-prefixed hardware repositories.

**Download the official Gerbers and order the board. This section is kept as a
reverse-engineering-versus-reality record.**

### ⚠️ Four things to know before you order it

**1. There is no charging circuit and no USB-C input on this board.**

The repository contains a `pwr_supply_charge.kicad_sch`, which makes it easy to assume the board
charges the battery. **It is an orphan sheet** — `main.kicad_sch` instantiates only
`audio / dynamixel / power / sensors`, never it, and its title block still reads
`Chromapi's Power Supply & Charge`, a leftover from another project.

Checked against the production BOM: `CN3302` (Li-ion charger), `HY2120` (protection), the USB-C
receptacle, the power switch, the indicator LEDs, `AO4435`/`FDS6630A` — **none of them are on it.**

Only two power parts are actually fitted:

| Ref | Part | Function |
|---|---|---|
| `U10` | **LM5050-1** | Ideal-diode controller (reverse protection / OR-ing) |
| `U9` | **AP63205** | Buck converter |

> **The battery must be charged with an external charger.** Plugging in USB-C will not charge the robot.

**2. Opening the KiCad project needs a second repository.**

The HAT repository has **no** `sym-lib-table`, no `fp-lib-table` and no `.pretty` directory, yet the
schematic references `Library_Pollen`, `LCSC_parts_lib` and `Lib_Pollen`. Those live in
[`pollen-robotics/lib_KiCAD`](https://github.com/pollen-robotics/lib_KiCAD).

Without it the project opens as a field of unresolved symbols.
**Not needed if you only want to fabricate** — use the Gerbers in `production/` directly.

**3. Four layers, 118 placements, assembly service required.**

The `kicad_pcb` layer stack is `F.Cu / In1.Cu / In2.Cu / B.Cu`. The BOM is 47 lines and 123 parts,
including a **VQFN-32 codec** and an **LGA-16 BMI088** — hand soldering is not realistic; order it
with SMT assembly.

Five DNP lines: `C25`, `R10/R11`, `R16/R17/R41`, `R36/R37`, and **`U4`**.

**4. `U4 = CAT24C32` is DNP → this is not a self-identifying HAT.**

The EEPROM position is left empty, so the board does not follow the `hat-plus-specification`
auto-detection flow. The device-tree overlay has to be applied by hand.

### Also: the Dynamixel side is dual-standard

| Ref | Interface | Note |
|---|---|---|
| `J13 / J14` | **TTL 3P** (JST EH 2.5 mm) | Microduck's XL330 servos use this |
| `J3 / J11` | **RS-485 4P** (JST EH 2.5 mm) | driven by `U8 = SIT3088E` |
| `TH1` | 100R thermistor | overcurrent protection |

So the board drives **both TTL and RS-485 Dynamixels, and Feetech servos**, with a cable change.

### Also: this is not a Microduck-only board

It is a general-purpose HAT for small and medium robots. Three known users:

- **Microduck** (this project)
- Pollen's own **Grabette / Casquette** (running on a Pi 4)
- Third-party **[`Rhoban/microban`](https://github.com/Rhoban/microban)** — a 19×XL330 + Pi Zero 2W
  + 2×18650 biped with a **complete public BOM, assembly and printing guide** (~$567 total).
  Worth cross-checking when sourcing parts.

> One line from `Rhoban/microban`'s BOM is worth remembering:
> *"Unlike the other components, the RPI Robot Hat is not an off-the-shelf part: it is an
> open-source board that you need to have manufactured."*
> — **open source ≠ purchasable.** You still have to fabricate it.

### Reverse-engineered conclusions checked against the official BOM

| Derived here | Actual official BOM | Result |
|---|---|---|
| Audio codec @ `0x18` | `U2 = TLV320AIC3104IRHBR` | ✅ |
| BMI088 @ `0x19/0x68`, fitted but unused | `U11 = BMI088` | ✅ |
| Pull-ups "a single 10k pair, **R12/R13**" | `R12, R13 = 10k` | ✅ **exact designators** |
| "Stemma **J5** connector" | `J5–J8 = JST SH 1 mm 4P` | ✅ |
| Pi Zero 40-pin form factor | `J4 = 2x20 rasp HAT zero SMD` | ✅ |

### What the source code could **not** reveal

| Part | Function |
|---|---|
| `U1 = PAM8406D` | Class-D audio amplifier |
| `MK1` | **On-board MEMS microphone** (LCSC `C7587901`). ⚠️ The official BOM only says `Microphone_MEMS`; the part number LMA2718 had no source and has been withdrawn |
| `U10 = LM5050-1` | Ideal-diode controller (reverse protection / OR-ing) |
| `AP63205` | Buck converter |
| `CAT24C32` | EEPROM — required by the Raspberry Pi HAT+ specification |
| `J1/J2/J9 = Wago-2` | Screwless terminals: external speaker and second microphone |
| `J3/J11`, `J13/J14` | Dynamixel 4P / 3P connectors (JST EH 2.5 mm) |

Two more facts from the official README that the source code does not carry:

- **Input range 5–28 V**, designed to be **powered through the motor connector**
- Dynamixel **TTL and RS485 both supported** (cable change only; drives Feetech servos too)

### What is on it

| Part | I²C address | Notes |
|---|---|---|
| **TLV320AIC3104** | `0x18` | TI audio codec, I²S data + I²C control |
| **BMI088** | `0x19` / `0x68` | **Actually fitted, but unused by software** (BOM `U11`; the comments say "dormant", "unused but still connected"). This is the second of the "two IMUs" the press mentions |
| **ToF** | `0x29` or `0x52` | Not on the board; via the **Stemma/Qwiic J5** header. The firmware supports **both VL53L5CX and VL53L8CX**, identified by revision ID |

- I²C bus: header **pins 3 and 5** (`GPIO1_A0` = SDA, `GPIO1_A1` = SCL)
- Bus speed **400 kHz** — capped by the codec and the BMI088; the VL53L5CX alone would
  take 1 MHz
- Pull-ups: **a single 10 kΩ pair, R12/R13**
- Audio clocks: **12 MHz** fixed MCLK, I²S system clock **12.288 MHz** (256 × 48 kHz)
- **The robot's internal power runs through this board** (battery → HAT → main board)

### ⚠️ A trap they hit themselves, documented in the overlay

The RK3566's `i2c3` controller runs in its **M1 pin mux** in the vendor DTB
(`GPIO3_B5/B6`, next to the USB-C port), where it serves the **FUSB302 USB-C PD
controller**. The pins the HAT needs — 3 and 5 — are that same controller's **M0 pin mux**.

Their overlay re-muxes the controller to M0 and disables the fusb302 node. Consequences:

- **USB-C PD negotiation is lost**
- But the FUSB302's power-on defaults already present Rd on both CC lines
  (`SWITCHES0 = PDWN1|PDWN2`), so USB-C chargers — PD or dumb — **still deliver 5 V**,
  and the board only ever wanted 5 V
- In-robot power comes from the battery through the HAT regardless
- maskrom flashing is ROM code and is unaffected

> An earlier revision used **bit-banged I²C** (`i2c-gpio-pihat`), which burned CPU in
> `udelay()` busy-waits. Moving to the hardware controller is what made the
> **15 Hz ToF stream** affordable. The two modes are mutually exclusive; `install.sh`
> selects between them with `MICRODUCK_I2C_MODE=hw|bitbang`.

### Stable device node

`/dev/i2c-3` is symlinked to **`/dev/i2c-pihat`** by a udev rule, so consumer code works
unchanged in either mode.

---

## 5. The Servo Bus

| Item | Value |
|---|---|
| Motors | **Dynamixel XL330 × 15** |
| Protocol | **Dynamixel Protocol V2** |
| Baud rate | **1 Mbps** (EEPROM register `baud_rate = 3`) |
| Serial port | `/dev/ttyS2` |
| Rust crate | [`rustypot`](https://github.com/pollen-robotics/rustypot) — Pollen's own |
| Control loop | **50 Hz** |

### ID assignment

```
Left leg    20  21  22  23  24    hip_yaw / hip_roll / hip_pitch / knee / ankle
Neck+head   30  31  32  33  34    neck_pitch / head_pitch / head_yaw / head_roll / mouth
Right leg   10  11  12  13  14    (mirror of the left)
IMU board   200                   imu_to_dxl v2
```

> **The 15th servo is the mouth (ID 34, index 9).** Every alpha policy is
> `obs[1,61] → actions[1,14]`, and the action vector **skips that index** — the mouth is
> driven by higher-level logic, not by the policy.
>
> This ID scheme is **identical to Open Duck Mini v2** (20-24 / 30-33 / 10-14), with only
> the extra 34 added. The lineage shows.

---

## 5b. Communications, Item by Item

### Main bus: single-wire half-duplex TTL UART — **not RS-232, not RS-485**

| Item | Value | Evidence |
|---|---|---|
| Physical layer | **3-wire TTL half-duplex** (data + VDD + GND) | XL330 spec: 3-pin JST, TTL |
| Logic level | **3.3 V** | RK3566 IO level |
| Protocol | **Dynamixel Protocol V2** | `.with_protocol_v2()` |
| Rate | **1 Mbps** | `BAUD_RATE = 1_000_000`, EEPROM `baud_rate = 3` |
| Port | `/dev/ttyS2` = RK3566 **UART2, M0 pin mux** | `robotd.toml`, `uart2-m0` overlay |
| Devices on the bus | **16**: 15 servos + 1 IMU board | `ids = [200, 20..24, 30..34, 10..14]` |
| Per transaction | one `sync_read` covering all 16 devices, registers **124–136** | `bus.rs` |

> ❗ **It is not RS-485.** RS-485 is a differential pair, used by Dynamixel's XM/XH series
> (4-pin). The XL330 is **single-wire half-duplex TTL** (3-pin). Searching the whole
> repository for `rs485|rs232|half-duplex|direction pin` returns **zero hits** — there is
> no direction-control GPIO in the code, which means **direction switching is done in
> hardware by a self-steering circuit**, and that circuit lives on the HAT.

### ⚠️ The Armbian trap: UART2 has a login console on it by default

> From `robotd-design.md`: Armbian runs `serial-getty@ttyS2` by default, and `agetty` holds
> the port. You must `systemctl mask serial-getty@ttyS2`. Pollen found this with
> `fuser -v /dev/ttyS2` naming `agetty`.

### Every interface at a glance

| Interface | Used for | Parameters |
|---|---|---|
| **UART2 (`ttyS2`)** | servos + IMU board | 1 Mbps, TTL half-duplex |
| **I2C3 (M0, pins 3/5)** | audio codec / ToF / (the unused BMI088) | 400 kHz |
| **I2S3 (`i2s3_2ch`)** | audio data | MCLK 12 MHz, sysclk 12.288 MHz |
| **MIPI CSI** | IMX219 camera | I²C control at `0x10` |
| **Bluetooth** | gamepad (`padd`), phone app (`btd`) | on-module |
| **Wi-Fi** | WebRTC video, provisioning (`configd`) | on-module |
| **USB-C** | power + maskrom flashing | PD negotiation sacrificed by the overlay |
| **Unix sockets** | JSON-RPC between daemons | not hardware |

---

## 5c. Why This Needs a Linux SoC and Not an STM32 or ESP32

The main board has to do all of this at once:

| Task | Load |
|---|---|
| ONNX Runtime policy inference | `obs[1,61] → act[1,14]` @ **50 Hz** |
| WebRTC video | 720p30 H.264, **Rockchip MPP hardware encoder** |
| RKNN NPU object detection | `duck_detect.rknn` @ 2 Hz — a **thermal limit**, 95 °C flat out |
| GStreamer pipeline + congestion control | `rtpgccbwe` costs 7.6 % of a core |
| Bluetooth gamepad + phone app + Wi-Fi | BlueZ stack |
| Signed firmware update / rollback | `updaterd` |

**An MCU cannot do this.** WebRTC plus H.264 hardware encoding plus ONNX inference alone
requires Linux, a hardware encoder and an NPU.

Hence the choice: **RK3566, quad Cortex-A55 + Mali-G52 + NPU, running Armbian**.

> 📌 Note, though, that **the prototype ran on a Raspberry Pi Zero 2W**. From
> `robotd.toml`: the 50 Hz control loop *"is inherited from the prototype, where it was
> chosen on a Raspberry Pi Zero 2W. It has never been re-derived on the Radxa."*
> Open Duck Mini v2 still runs on a Pi Zero 2W today — because it does no vision and no
> WebRTC.

### So what MCU is on the `imu_to_dxl` board?

**Not in the repository** — that is the board's own firmware, which is not open source.
But its job defines the requirements:

- Act as a **Dynamixel Protocol V2 slave** (answer `sync_read`, ID 200, register 124)
- Read the **LSM6DSV16X** (SPI or I²C)
- Sustain **1 Mbps UART** with half-duplex direction switching
- Pack the SFLP quaternion into fp16

**An STM32G0, STM32G4, CH32V203 or ESP32 are all sufficient.** This is exactly the place
where you are free to choose — as long as it behaves like a Dynamixel slave on the wire,
the host does not care what is inside.

---

## 6. Power and Battery

| Item | Value |
|---|---|
| Battery | **Sony NP-F550** (L-series camcorder pack), **2S Li-ion** |

> ⚠️ **It is an NP-F550, not an F970.** The upstream mesh is named `np_f970`, but its bounding box
> measures **70.8 × 38.6 × 20.6 mm** — NP-F550/F570 size — and the source only ever names the F550.
> A real NP-F970 is ~60 mm thick and ~300 g: **it does not fit and blows the weight budget.**
> See [BOM](../BOM.en.md).
| Nominal | 7.2 V |
| Full, under load | **8.2 V** |
| Empty, under load | **6.6 V** |
| Fuel gauge | **none** |
| ADC | **none** |

### How the voltage is measured

> From the source: *"There is no fuel gauge and no ADC. The only measurement available is
> what the servos report as their own supply."*

The pack voltage is read **over the Dynamixel protocol, from what the servos report as
their own supply** — the battery as seen through the bus. That means the reading **sags
under load and recovers at rest**, so the 6.6–8.2 V span is a **usable-under-load range**,
not the cells' chemical range.

When the battery EMA (about a 10-second time constant) reaches 6.6 V, the robot
**sits down gracefully and powers off**.

> Good news for anyone reproducing this: **you do not need any battery-monitoring circuit
> at all.**

---

## 7. Sensors

### ToF depth

| Item | Value |
|---|---|
| Chip | **VL53L5CX** or **VL53L8CX** (ST multizone ranger; two generations, one interface) |
| Address | `0x29` |
| Bus | the HAT's i2c3 |
| Frame rate | 15 Hz |

Used for the `theremin` feature: the distance of a hand in front of the beak maps to a
pitch, and the mouth opens with it. Playable band 0.10–0.70 m.

### Camera

| Item | Value |
|---|---|
| Sensor | **IMX219** (= Raspberry Pi Camera v2) |
| I²C address | `0x10` |
| Device-tree overlay | `radxa-zero3-rpi-camera-v2` |
| Mounting | **a quarter turn off** — `mediad/src/main.rs:82` defaults `--rotate` to **90**.<br>⚠️ The 180° in `docs/project/media-bringup.md:472` is **alpha-unit** data. |
| Sensor mode | pinned to 1920×1080@30 (its boot mode caps capture at 21 fps) |
| Default output | 720p30, 2 Mb/s |
| Encoding | GStreamer + **Rockchip MPP hardware encoder** → WebRTC |
| HFOV | ~62° |

### Audio

| Item | Value |
|---|---|
| Codec | TLV320AIC3104 |
| ALSA card name | `aic3104` |
| Microphone | on **Mic3R** (mono, right PGA); every other input is switched off |
| Output | line out, volume 9/9 |

---

## 7b. The NPU and On-Board Vision

> Compiled from upstream `docs/project/npu-bringup.md` and `duck-detect/`.
> It is currently the only material that states plainly what the RK3566's NPU can actually do.

### NPU specification

| Item | Value | Source |
|---|---|---|
| Compute | **0.8 TOPS, INT8, single core** | opening of `npu-bringup.md` |
| Device-tree node | `npu@fde40000` | Armbian ships it `status = "disabled"` |
| Runtime | rknn-toolkit2 runtime, `librknnrt.so` | driver 0.9.8 / runtime 2.3.2 (measured) |

### ⚠️ Two hard constraints that will stop a replica dead

**1. The driver exists only in the vendor kernel. Mainline has none.**

> Upstream: *"The driver is the gate: it is part of the vendor kernel, mainline has none,
> and nothing in userspace can work around its absence."*

This is far more serious than "the NPU is off by default". Swap in a mainline-kernel distro —
which most official Debian/Ubuntu images are — and **the NPU simply is not there, with no
userspace workaround**. The OS image is not a free choice when reproducing this robot.

**2. Armbian disables the NPU node on every Radxa Zero 3.**

So a stock board has the hardware, the kernel and the driver, and still **no NPU**.

```bash
# Upstream runs this from the preinstall hook on every robotctl update, non-fatally
sudo sh /opt/robot/daemon/current/scripts/setup-npu.sh
# writes the overlay -> reboot required -> confirm with:
dmesg | grep rknpu
```

Run the copy **inside the release**, not `/usr/local/sbin/robot-setup-npu`: the overlay source
lives beside the script, and the standalone copy has nothing beside it on a first run.

### The duck detector

The model is trained in a separate repository, `pollen-robotics/duck_detector`, and arrives here
already quantised as `.rknn`.

> ⚠️ **That repository is not public** (404 as of 2026-09-04). Upstream docs reference it, but the
> training code is not obtainable — only the finished `.rknn`. Training your own means building a
> YOLO pipeline from scratch.

| Item | Value |
|---|---|
| Network | `yolo11n` @ **320×320** |
| Classes | **1** (the duck) |
| Training set | **150 frames from 3 sessions** |
| mAP50 | **0.976** on a held-out session |
| Size after INT8 quantisation | **3.9 MB** |
| Quantisation loss | 2 of 2 detections kept at 95% box overlap vs the float model, on the desk |

> 0.976 from 150 frames — single class, fixed subject, constrained scene. That data
> requirement is good news for anyone reproducing this.

### Measured performance (Radxa Zero 3, paced 2 Hz, 30 frames over 3 passes)

| Item | Measured | Note |
|---|---|---|
| Latency p50 / p95 | **25.7 ms / 58.4 ms** | inference plus decode, not JPEG decoding |
| CPU per frame | 20.7 ms | **not the NPU's cost** — see below |
| SoC temperature | **63 °C** | at the end of a paced run |

**That CPU figure invites misreading.** The latency column times `infer` + `decode`; the CPU
column is the whole loop's process CPU divided by frames, so it **also carries `letterbox_rgb`**
— a 1280×720 → 320×320 resample that runs on the CPU and is not in the latency column at all.
Whether the remainder means `rknn_run` busy-waits (charging NPU wait to the CPU) is not yet known
upstream either.

> At 2 Hz it is **4% of one core** either way. But before anyone quotes that as the price of
> perception, the two should be measured apart.

For why the rate is 2 Hz, see [§8, Two engineering details worth stealing](#two-engineering-details-worth-stealing)
— it is a **thermal limit, not a preference**; running flat out reaches 95 °C.

### Three engineering decisions worth stealing

**1. `dlopen`, not link.** `librknnrt.so` is a vendor blob in no Debian suite, and a crate that
linked it could not be cross-compiled in CI. The cost is `duck-detect/src/rknn.rs`; the benefit is
that `cargo board --bins` still works on a laptop. `robotd` reaches ONNX Runtime the same way.

**2. Let the runtime dequantise.** A quantised model's output tensor is int8 with a scale and a
zero point. `rknn_outputs_get` will convert to float if asked, and upstream asks — the alternative
is carrying the scale into the decoder and **getting it wrong once, quietly**.

**3. Triage in the order that matters: does it run → does it still see → what does it cost.**
`duck-bench` reports in exactly that order. A model that runs and detects nothing looks exactly
like one that works.

> ⚠️ **A quantised model's scores are on their own scale.** The float model's 0.5 is not this
> model's 0.5. When it detects nothing, try `--threshold 0.2` before believing the conversion
> is broken.

### What is still missing

**Nothing on the robot can get a frame.** `mediad` has a raw NV12 tee branch that exists precisely
for this, but **no IPC exposes it** — which is also why capturing a dataset has to stop `mediad`
to take the camera.

Upstream names two ways forward, not exclusive: add a `media.frame` call that answers with one
frame; or put the detector inside `mediad`, subscribing to the raw branch, running at a few Hz and
publishing detections on the state stream.

> The second is where it ends up: **perception next to the sensor, deriving features rather than
> shipping pixels.**

### What this means if you are reproducing it

1. **The OS image is not a free choice** — it must carry the Rockchip vendor kernel (Armbian family)
2. First thing after you get a board: **enable the NPU node and reboot**, or every inference runs on the CPU
3. Training your own model starts at roughly **150 frames** for usable accuracy — a lower bar than expected
4. Do not plan on pulling frames off the robot for your own work yet — **upstream has not finished that path**

---

## 8. Software Parameters You Must Match

| Parameter | Value | Notes |
|---|---|---|
| Control loop | **50 Hz** | inherited from the Pi Zero 2W prototype; **never re-derived on the Radxa** |
| Policy interface | `obs[1,61] → actions[1,14]` | checked at load; the older 51-D family is refused |
| `action_scale` | 0.9 (walk) / 0.8 (roller) | |
| Position P gain | **200** | ×0.8 while standing |
| Action low-pass | head **0.5** / legs **0.7** | **must match training**, or transfer degrades |
| Voltage adaptation | off by default | when on: `scale × (7.4 / measured EMA)`, clamped 6.0–9.5 V |

### Two engineering details worth stealing

**1. Predictive soft landing (`limp_fall`)**

It does not wait for the fall. Projected gravity rotates with the trunk, so its rate of
change is exactly `-(ω × g)` — and the gyro in that same 12-byte IMU block is used to
extrapolate **300 ms** ahead. When the robot is **already** tilted past about 26°,
**is still tipping rather than recovering**, and the extrapolation lands past the
threshold, the gain drops from 200 to **50** so the joints give way instead of fighting
the floor, and the robot **arrives limp**. Once it has gone still — judged from the gyro,
not a timer — the pose is ramped back to standing over 600 ms, and only then handed back
to the standing policy.

> The rationale in the source is worth quoting: the standing policy is *"a good
> stand-up-er and a bad faller"*. From a still robot, face down or face up, it gets back
> on its feet cleanly; out of a dynamic fall it tries and fails and tries again, at
> walking gain, against the floor — and the motors pay for every attempt.

**2. The 2 Hz detection rate is a thermal limit**

> From the source: *"2 is a thermal limit, not a preference."* Flat out it reaches
> **95 °C** and the CPU throttles to **408 MHz** — a robot that walks badly in order to
> see well.

---

## 9. What It Takes to Reproduce This Electronics Stack

### ✅ Buy off the shelf

| Part | Model | Notes |
|---|---|---|
| Main board | **Radxa Zero 3W** | stock module, **not custom** |
| Servos | Dynamixel XL330 × 15 | |
| Battery | **Sony NP-F550** + holder | common camcorder pack. **Not the F970 — it does not fit** |
| Camera | Raspberry Pi Camera v2 (IMX219) | |
| ToF | VL53L8CX module (Stemma/Qwiic) | |

### 📥 One board you simply download

**RPI Robot HAT — do not draw it.**
[`pollen-robotics/elec_RPI_Robot_HAT`](https://github.com/pollen-robotics/elec_RPI_Robot_HAT)
(Apache-2.0) ships a `production/` folder with Gerbers, BOM and pick-and-place. Order it as is.
Note it is a **4-layer** board.

If you want to simplify (no microphone, no speaker), you can also skip it entirely: put a stock
VL53L8CX module straight onto i2c3 and use an off-the-shelf 5 V UBEC for power.

### 🔧 The one board you must build yourself

**`imu_to_dxl`** — no public project exists anywhere, so this is the only board that has to be
rebuilt from scratch. LSM6DSV16X + a small MCU (Dynamixel V2 slave) + a half-duplex TTL
transceiver. The protocol and 12-byte register layout are given in full above; implement to that.

### ⚠️ Traps to plan for

1. **i2c3 collides with the FUSB302** — using the hardware I²C on pins 3/5 costs USB-C PD
   negotiation (plain 5 V charging still works). See section 4.
2. **The NPU ships disabled** — Armbian does not enable it; flash the overlay and reboot
   before running RKNN models.
3. **The camera is mounted a quarter turn off** — set `rotate=90` and let the hardware encoder
   do it; do *not* use `videoflip`, which is a full CPU pass over every frame.
4. **The 50 Hz loop was never validated on the Radxa** — Pollen say so themselves; the
   number came from the Pi Zero 2W prototype.

---

## 10. Conclusion: This Electronics Stack Can Be Reproduced

An earlier version of this document concluded "the RK3566 carrier is custom and
unobtainable, the PCB is a hard wall." **That conclusion was wrong:**

- The main board is an **off-the-shelf Radxa Zero 3W**, not a custom carrier
- Of the two custom boards, `imu_to_dxl` has very few components and its protocol is now
  fully recovered — it is straightforward to build
- **The HAT board is fully published by Pollen** (KiCad + Gerbers + BOM) — no need to draw it

**What actually remains is software.** The Rust runtime is open source (Apache-2.0) but
bound to the Radxa Zero 3W's specific wiring — so if you build around the same main board,
**the runtime runs as-is.**

> Sources: `duck-control/src/{model,imu,bus}.rs`, `robotd/src/main.rs`,
> `deploy/robotd.toml`, `deploy/audio/*.dts`, `deploy/overlays/*.dts`,
> `tof/src/*.rs`, `mediad/src/*.rs`, `docs/design/robotd-design.md`,
> `docs/project/media-bringup.md` — all in `pollen-robotics/microduck`.

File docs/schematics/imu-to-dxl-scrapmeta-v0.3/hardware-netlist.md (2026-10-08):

# Hardware — imu_to_dxl_ref **v0.3**

> **现行 PCB / 原理图真源：**  
> `hardware/imu_to_dxl_ref_2026-08-30_18-59-47.eprj2`（嘉立创专业版）  
> 丝印：`imu-to-dxl v0.3` · 板框 **32×22 mm** · 四角 φ2.2 · 孔距 **29×19**  
> Wiki：`board-imu-to-dxl` · `imu-to-dxl-ref-schematic` · `imu-to-dxl-ref-bom` · `imu-to-dxl-ref-chip-wiring`  
> `_backup/` 与旧 `.epro2` **仅对照，勿覆盖定稿**。

总线契约（不变）：DXL **ID 200** · addr **124** · **1 Mbps** · PHY **SN74LVC1G125**。

---

## v0.3 vs v0.2（硬件）

| 项 | v0.2 | v0.3 |
|----|---|---|
| DXL 座 | 单 J1 EH | **J1 进 + J3 出**（并联） |
| 调试 | BM04 4P SWD；NRST→TP1 | **BM07 7P**（SWD+UART+NRST）；无 TP1 |
| 总线保护 | DATA 上 TVS | 座侧 **`DXL_BUS`**：D1 TVS + D2 5.1 V；**R6 150 Ω** → 芯片侧 **`DXL_DATA`** |
| 上拉 | 主要 R1 NRST | **R1–R5**：NRST / CS / OE# / DATA / UART_RX |
| 电源电容 | C1–C5 | +**C6 4.7 µF** on +3V3 |
| MCU 控制脚 | 同左（DXL/SPI/SWD） | **同**；另引出 **USART1** 到 J2 |

固件仍用 USART2+SPI1+PA1 OE#；USART1 仅调试口，可选启用。

---

## 连接器

### J1 / J3 · B3B-EH-A（DXL）

| Pin | 网名 |
|-----|---|
| 1 | GND |
| 2 | VBATT |
| 3 | DXL_BUS（DATA） |

叶节点可只插 **J1**，J3 空着。穿板 `VBATT` 宜 ≥40 mil / 铺铜。

### J2 · BM07B-SRSS-TB（调试 · LCSC **C160393**）

| Pin | 网名 | MCU | 丝印 |
|-----|---|-----|---|
| 1 | +3V3 | — | 3V3 |
| 2 | SWCLK | PA14 | CLK |
| 3 | SWDIO | PA13 | DIO |
| 4 | GND | — | GND |
| 5 | UART1_TX | **PA11** | TX |
| 6 | UART1_RX | **PA12**（R5↑） | RX |
| 7 | NRST | PF2-NRST（R1↑） | RST |

---

## MCU 脚位 ↔ 网络（firmware-relevant）

STM32G031F8P6 · TSSOP-20

| MCU 脚 | 信号名 | 网络 / 去向 |
|---|---|---|
| 4 | VDD | +3V3 |
| 5 | VSS | GND |
| 6 | PF2-NRST | NRST · J2-7 · R1↑ |
| 7 | PA0 | IMU_INT ← U1 INT1 |
| 8 | PA1 | **DXL_OE#** → U6 OE# · R3↑ |
| 9 | PA2 | **USART2_TX** → U6-A |
| 10 | PA3 | **USART2_RX** ← `DXL_DATA` · R4↑ |
| 11 | PA4 | SPI1_NSS / **SPI_CS** → U1 CS · R2↑ |
| 12 | PA5 | SPI1_SCK → U1 SCL |
| 13 | PA6 | SPI1_MISO ← U1 SDO |
| 14 | PA7 | SPI1_MOSI → U1 SDA |
| 16 | PA11 | **USART1_TX** → J2-5 |
| 17 | PA12 | **USART1_RX** ← J2-6 |
| 18 | PA13 | SWDIO → J2-3 |
| 19 | PA14 | SWCLK → J2-2 |
| 2 / 3 | PC14 / PC15 | LSE（Y1/C7/C8 **DNP**） |
| 1 / 15 / 20 | — | NC |

半双工规则：`PA1` 低 = U6 驱动总线（TX）；高 = 高阻（RX）。发完立即回 RX。

---

## 电源 / 保护

```
J1-2 ∥ J3-2 ── VBATT ──┬── U3 AP2210 VIN/EN
                       ├── C5 10µF 50V · C4 100n ── GND
U3 VOUT ── +3V3 ── C2 1µF · C6 4.7µF · MCU/IMU/U6/J2

J*.3 ── DXL_BUS ──┬── D1 PESD · D2 5V1 ── GND
                  └── R6 150Ω ── DXL_DATA ── U6-Y · PA3 · R4↑
```

---

## LSM6DSV16X SPI（DS13510）

| MCU | LSM6 脚 | 名 |
|-----|---|-----|
| PA6 MISO | **1** | SDO/SA0 |
| PA7 MOSI | **14** | SDA |
| PA5 SCK | **13** | SCL |
| PA4 CS | **12** | CS（+ R2 10k↑） |
| GND | **2 / 3** | SDx / SCx（辅口，须接地） |

Gyro 满量程必须 **±500 dps**（与 `duck-control` 一致）。

---

## 时钟

TSSOP-20 无 HSE：默认 **HSI → PLL → 64 MHz**（或 bring-up 用 16 MHz HSI）。LSE 占位不焊。

---

## 仓路径

`microduck-diy/imu_to_dxl/`（已自 `microduck_imu_to_dxl/` 物理改名）。

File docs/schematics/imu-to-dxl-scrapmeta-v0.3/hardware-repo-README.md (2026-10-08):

# Hardware source of truth (v0.3)

| 项 | 值 |
|----|-----|
| 工程 | **`imu_to_dxl_ref_2026-08-30_18-59-47.eprj2`** |
| 丝印 / 板 | `imu-to-dxl v0.3` · 32×22 mm |
| 文档 | 见上级 `docs/hardware.md`（脚位表）· `docs/protocol.md` |
| BOM | wiki `imu-to-dxl-ref-bom` · 立创 `BOM260909006316` / `SO26090921960` |

`*_backup/` 与旁路 `.epro2`：**只读对照**，不以之覆盖定稿。

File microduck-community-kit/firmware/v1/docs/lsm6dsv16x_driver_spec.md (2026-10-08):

# LSM6DSV16X 驱动规格（imu_to_dxl v1 / GD32F303CC）

面向实现：把 ST **LSM6DSV16X**（SPI0，PA4=CS/PA5=SCK/PA6=MISO/PA7=MOSI，INT1=PB0，
INT2=PB1）接到现有 100 Hz 主循环上，产出与 `src/imu.h` 一致的 20 字节块。

  本文档每个寄存器号/位域/常数都给出 `§节号 / Table 号`。凡数据手册文本无法确认的，
  一律标注 **【不确定/需查原图】**，不猜。
* 交叉参考（**不作为数字依据**）：`src/imu.h` / `src/imu_sim.c` / `src/imu_math.h`
  （20 字节块与 half 编码的既有约定）、`src/board.h`（引脚与标志位）；
  `TELEM_FLAG_*` 的语义见 `docs/imu_to_dxl_protocol.md` §6.4。
* 目标 20 字节块（`src/imu.h`、`board.h TELEM_LEN=20`）：

| 字节 | 内容 |
|---|---|
| 0..6 | `gyro x/y/z` int16 LE，**chip frame**，±500 dps @ **17.5 mdps/LSB** |
| 6..12 | `quat x/y/z` IEEE binary16，`w = √(1−x²−y²−z²)` |
| 12..18 | `accel x/y/z` int16 LE，**chip frame**，±4 g @ **0.122 mg/LSB** |
| 18 | `counter` u8 |
| 19 | `flags`（`TELEM_FLAG_*`） |

---

## 1. 身份与接口

### 1.1 身份

| 项 | 值 | 出处 |
|---|---|---|
| `WHO_AM_I` 地址 | **0x0F** | Table 24（寄存器地址映射表） |
| `WHO_AM_I` 期望值 | **0x70** | §9.13 "Its value is fixed at 70h"；Table 49 位图 `01110000`；Table 24 默认列 `01110000` |
| 辅助 SPI 的同名寄存器 `SPI2_WHO_AM_I (0Fh)` | 也是 **0x70** | §11.1 "Its value is fixed at 70h" |
| 读类型 | R（只读） | Table 24 / §9.13 |

**注意**：主接口与辅助 SPI（SPI2）的 `WHO_AM_I` 都是 `0x70`，因此 `WHO_AM_I` **不能**
区分"读到的是主接口还是辅接口"。本板只接主接口（mode 1，见 §1.5），读到的就是主接口页。

### 1.2 SPI 电气与帧协议

| 项 | 值 / 结论 | 出处 |
|---|---|---|
| 角色 | SPI **从机**（MCU 为主机），全双工 4 线 | §5.1.3 "The SPI on the LSM6DSV16X is a bus slave" |
| 帧宽 / 位序 | 8 bit，**MSB first** | §5.1.3 bit0=RW、bit1-7=AD(6:0)、bit8-15=DI/DO(7:0) |
| SPI 模式 | **Mode 3**（CPOL=1, CPHA=1）：SPC 空闲为高；SDI/SDO 在 SPC 
**下降沿**驱动、**上升沿**采样 | §5.1.3 明文字；GD32 宏 `SPI_CK_PL_HIGH_PH_2EDGE`。Mode 0 亦被支持（Table 7 给出 mode 0 的 `tsu(CS)`），但本设计用 Mode 3 |
| 最短帧 | **16 个 SPC 脉冲**（1 字节地址 + 1 字节数据）；多字节按 8 位块追加 | §5.1.3；§5.1.3.1；§5.1.3.2 |
| 读位 | bit0 = **1**（READ） | §5.1.3.1 "bit 0: READ bit. The value is 1." |
| 写位 | bit0 = **0**（WRITE） | §5.1.3.2 "bit 0: WRITE bit. The value is 0." |
| 地址字段 | bit1-7 = `AD(6:0)`，**7 位**（0x00–0x7F） | §5.1.3 |
| 地址自增 | `CTRL3(0x12).IF_INC = 1` 时多字节访问地址**逐块自增**；`=0` 时地址保持 | §5.1.3；§9.16 / Table 57 |
| **dummy byte** | **不需要**。文本中 **没有** dummy byte 的说明（全文 grep "dummy" 无命中）：读帧 bit8-15 直接就是 `DO(7:0)`，"the chip drives SDO at the start of bit 8" | §5.1.3；§5.1.3.1 与 Figure 11/12 |
| 最大 SPC 频率 | **10 MHz** | Table 7 `fc(SPC)` max 10 MHz |
| 时序余量 | `tc(SPC) ≥ 100 ns`、`thigh/tlow ≥ 45 ns`、`tsu(CS) ≥ 5 ns`（mode 3）、`th(CS) ≥ 20 ns`、`tv(SO) 15–25 ns`、`tdis(SO) ≤ 50 ns`、`Cload ≤ 100 pF` | Table 7 |
| 3 线 / 4 线 | `IF_CFG(0x03).SIM`：**0 = 4 线**（本板）、1 = 3 线 | §9.3 / Table 30 |
| CS 极性/含义 | CS 低有效；"1: SPI idle mode / I²C…; 0: SPI communication mode" | §3.1 / Table 2（Pin 12） |

**【不确定/需查原图】**：Figure 10/11/12 的位级波形在文本抽取中只剩标签，未逐条比对。
Mode 3 的结论来自 §5.1.3 的文字（"SPC … is stopped high when CS is high"、"driven at the
falling edge of SPC and should be captured at the rising edge"），**台面仍需用逻辑分析仪
在 Mode 3 下确认一次**（见 §9）。

**SPI 时钟选择（本板数字）**：`system_gd32f30x.c` 设 AHB=SYSCLK、**APB2 = AHB/1 = 120 MHz**
（`RCU_APB2_CKAHB_DIV1`），SPI0 挂在 APB2。GD32 分频只有 2 的幂：

| `spi_parameter_struct.prescale` | SPI0 SCLK | 结论 |
|---|---|---|
| `SPI_PSC_32` | **3.75 MHz** | 点亮/排障档，最稳 |
| `SPI_PSC_16` | **7.5 MHz** | **推荐工作档**（10 MHz 上限内，留 25% 余量） |
| `SPI_PSC_8` | 15 MHz | **超规格，禁止** |

一次寄存器读只需 2 字节（地址+数据），一次 12 字节突发读 13 字节；7.5 MHz 下
13 字节 ≈ 13.9 µs，对 100 Hz 主循环无影响。
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

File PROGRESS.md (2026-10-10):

# 进度记录

事实性的进度流水：什么时候到了什么、做了什么。核对结论与安全边界见 [README](./README.md) 与 [BOM](./BOM.md)。

## 参考库使用规则（2026-10-09 起）

**`microduck-replica/`、`microduck-community-kit/`、`microduck-build-tutorial/` 是别人的方案，只读参考，不在里面做任何修改。** 自己的进度、笔记、补丁一律放工程根目录（本文件、`docs/`、`local-changes/`）。历史上混入参考库的本地修改已于 2026-10-09 提取到 [local-changes/](./local-changes/) 并把参考库还原为上游原样：

| 参考库 | 上游 | 本地状态 | 校验（2026-10-09，逐文件 SHA256，忽略 CRLF/LF） |
|---|---|---|---|
| microduck-replica | fanhao375/microduck-replica `master` | 固定提交快照 `0f2cff6bd7`（2026-09-28，444 文件，与 README 记录一致） | 还原后与该提交 **0 新增 / 0 缺失 / 0 差异** |
| microduck-build-tutorial | AI-FanGe/Microduck-build-tutorial `main` | 内容等于 2026-10-09 上游 main | 还原后 **0 新增 / 0 缺失 / 0 差异** |
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

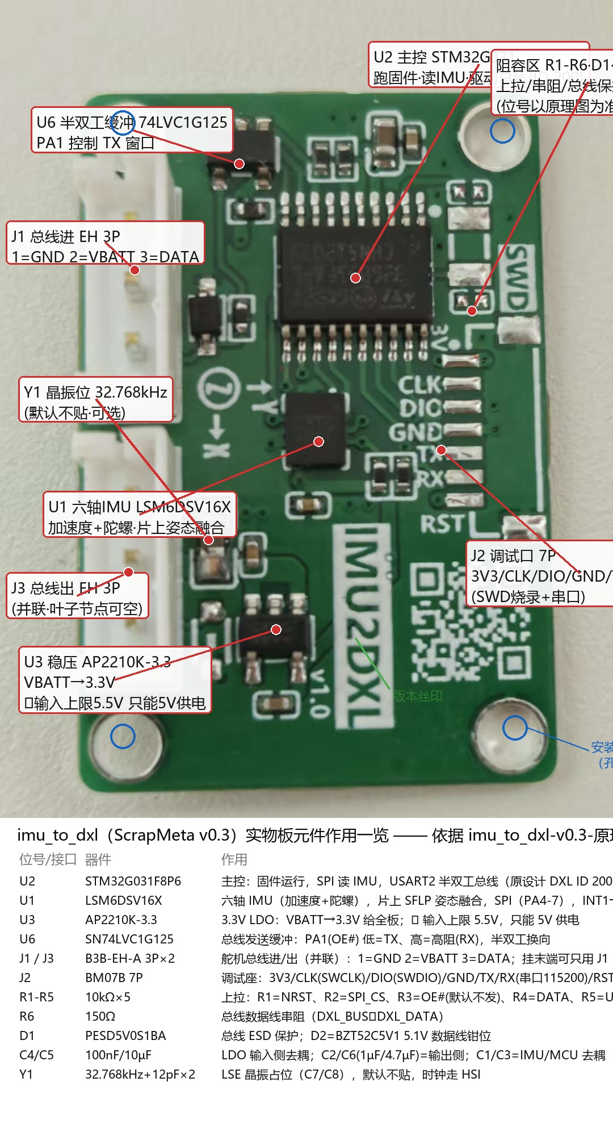
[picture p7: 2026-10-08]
docs/schematics/imu-to-dxl-scrapmeta-v0.3/实物板元件标注.jpg

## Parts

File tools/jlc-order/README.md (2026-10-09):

# jlc-order：嘉立创官方 API 自动下单工具（PCB 打样）

基于 [嘉立创开放平台](https://open.jlc.com) 官方 API 的命令行工具，把
「Gerber 打包 → 上传 → 计价 → 确认 → 下单 → 跟进度」整条 PCB 打样流程脚本化。
运行时**零第三方依赖**（纯 Python 标准库），Python ≥ 3.11。

## 快速开始

```bash
cd tools/jlc-order
cp config.example.toml jlc-order.toml   # 填入你的 appid / AccessKey / SecretKey
uv sync                                 # 仅测试/开发需要；日常直接用系统 python 即可
uv run python -m jlc_order doctor       # 自检：验签、IP 白名单、时间同步
```

密钥来源：open.jlc.com → 控制台 → 创建应用（一键生成）。
也可以用环境变量 `JLC_APP_ID` / `JLC_ACCESS_KEY` / `JLC_SECRET_KEY` 提供密钥。

## 命令一览

```bash
python -m jlc_order doctor                                   # 自检
python -m jlc_order pcb quote -p examples/banana_pcb.toml    # 在线计价（无需文件）
python -m jlc_order pcb order -p examples/banana_pcb.toml \
        [--file-url <url>] [--yes|--dry-run]                 # 创建订单
python -m jlc_order pcb reorder --order-no <customerOrderId> [--yes]      # 返单
python -m jlc_order order get --order-no <customerOrderId>   # 订单信息
python -m jlc_order order progress --order-no <customerOrderId> [--watch] # 进度/轮询
python -m jlc_order pcb quick --project ../../hardware/banana_pcb \
        -p examples/banana_pcb.toml [--yes]                  # 打包校验→计价→确认→下单
python -m jlc_order ledger                                   # 最近调用台账
```

参数模板见 `examples/banana_pcb.toml`（banana_pcb 电池转接板，39.2×6.8mm 双层板）。
下单信息（资料 URL/收货人/发票/快递）配置在 `jlc-order.toml` 的 `[order]` 段，
注释模板见 `config.example.toml`；`order get/progress/reorder` 的单号是整数
`customerOrderId`（`--order-type examples|batch`，样板默认 examples）。

## 安全机制

- **下单/返单/quick 默认交互确认**，`--yes` 显式跳过；非交互环境没有 `--yes` 会直接拒绝。
- **`--dry-run` 零网络发送**（有专门测试保证），打印签名后的完整请求供检查。
- 下单类接口**失败不自动重试**（防重复下单）；查询类接口失败自动重试。
- 密钥只存 `jlc-order.toml`（已 gitignore）或环境变量；日志/台账/dry-run 输出一律脱敏。
- 每次调用追加写入 `orders.jsonl` 台账（接口、状态、业务码、J-Trace-ID），
  报障时把 J-Trace-ID 提供给官方客服（18665386054）。

## 接口对齐状态

**2026-10-09 已对齐并线上验证**：签名（JOP/HmacSHA256）、网关、14 个已授权 PCB 接口。
路径出自官方 PCB 业务 SDK jar（控制台→SDK下载）与各接口 PDF 文档
（已下载到 `api-docs/`，gitignore，重下入口：控制台→应用管理→管理→查看文档）。

- 计价全链路已通：`pcb quote` 用工艺参数即可算价（无需文件），实测返回真实价格。
- **下单全链路已实测跑通**（2026-10-09 首单 customerOrderId 85073604）：文件以
  `pcbFileUrl`+`fileName` 传入（开放平台无上传接口；用百度网盘分享链接，上传/分享
  脚本见 `tools/baidu-pan-mcp/`）；联系人/收货信息按官方示例明文提交；`advancePayment=false`
  默认只建单不扣款。API 下单三个坑（都已内置处理）：`charFontColor` 下单必填、
  个人发票必须 `invoiceType="personal"`、**快递 JYM 会被拒需用 SF_DSBZ_JF 等**。
  使用前在 `jlc-order.toml` 补 `[order]` 段（见 `config.example.toml`）。
- 应用（microduck-replica）当前只开通了 PCB 业务线；3D 打印另有独立接口
  （`/3dp-open/order/uploadModelFile`、`submitOrder` 等，3DP 业务 SDK 可从控制台下载），
  需在控制台为应用加开 3DP 业务线后可用。

## 常见问题

- **401 验签不通过**：检查 secret_key 是否复制完整、系统时间是否准确（秒级校验）。
- **403 请求被拒**：多为 IP 白名单未放行本机出口 IP，去控制台→应用管理→IP 白名单添加，或关闭白名单。
- **新客免费打样**：API 下单是否叠加平台优惠由平台决定，本工具不承诺价格。
- **Windows / WSL**：纯标准库实现，两边都能跑；`uv run` 会自动用本项目 `.venv`。

## 测试

```bash
uv run pytest        # 33 个用例：官方签名 golden、dry-run 零发包、确认闸门等
uv run ruff check .
```

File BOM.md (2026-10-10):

# BOM 采购清单（当前路线：C · 飞特）

> **2026-10-10 重写**：2026-10-09 路线定稿「主参考 = community-kit 飞特路线」（HD-1910-C001 + HAT + imu_to_dxl 总线从站，见 [PROGRESS](./PROGRESS.md)「方案方向」）。本文件替换原根目录 A 线清单（XL330 + OpenRB + Pi Zero，2026-09-28 编写），A 线清单原样存档于 [docs/bom-route-a-20260928.md](./docs/bom-route-a-20260928.md)——仅当回退 A 线时使用。
>
> 状态口径：`[x]` 到货并登记 · `[~]` 在途/已下单 · `[ ]` 未购或待定。供电口径按 [docs/power-architecture-v2.md](./docs/power-architecture-v2.md)：**电池直通是唯一动力母线，舵机/HAT/IMU 全部吃电池原电压，5V 只存在于 HAT 板内**。

## 核心件

| 状态 | 物料 | 数量 | 用途 | 状态说明 |
| :---: | :--- | :---: | :--- | :--- |
| [x] | 飞特舵机 HD-1910-C001（预期型号） | 15（含嘴） | 关节 | 在手**待清点**：型号/数量/出厂 ID（预期出厂全 ID 1，需逐个设 ID） |
| [x] | 白色鸭图案 HAT | 1 | 主控适配 + 总线物理层（74LVC 半双工 + UART2/ttyS2） | 实物丝印 **V1.2**（10-10 照片确认）；存档原理图为 V1.0，图物差异大（多 F303 类 MCU + 超级电容），**V1.2 图纸待向板卡来源索取**；电气功能按 [docs/hat-v1.2-test.md](./docs/hat-v1.2-test.md) 操作单验证 |
| [x] | IMU 板 imu_to_dxl | 1 | 姿态总线从站（DXL ID 200，双协议） | 确认 ScrapMeta microduck-diy **v0.3**（STM32G031，LDO=AP2210K-3.3 耐 13.2V，**直挂总线**）；待 J2 焊接 → DAPLink 刷机 → imu200 验收（[flash/README](./flash/README.md) 固件包已备），上台架做一次 8.4V 供电验证 |
| [x] | BUS SERVO POWER SUPPLY V1.3 降压板 | 1 | **可选**转接件：XT60 ↔ 螺丝端子 | 空载实测完成（6V 档/下限 ≈6.3V/直通可用）。架构 v2 后**降为可选**：VCC 稳压口闲置不动，拿掉它则自制线直连 HAT |
| [x] | 微雪 Bus Servo Adapter (A) | 1 | 半双工总线转接（台架调试） | 待上机验证，对比飞线方案 |
| [~] | banana_pcb ×5 | 5 | 电池触点取电转接 | 订单 85078132 已下单；到货后装配（焊 U6068 → locker 打印 → 核极性 → 主控支路验证） |
| [~] | DAPLink SWD 调试器 | 1 | IMU 刷机链路 | 在途 |
| [~] | U6068 插针 | 2 | banana_pcb 电池触点 | 在途 |
| [~] | 2S 电池（NP-F550，8.4V） | 1 | 动力 + 逻辑总电源 | 在途；到货登记触点形式，与 banana_pcb 装配一起定供电终案 |

## 供电与充电

| 状态 | 物料 | 说明 |
| :---: | :--- | :--- |
| [ ] | **匹配充电器** | 与 NP-F550 配套；无采购记录，**需确认是否已有** |
| [ ] | **保险丝 5A + 座** | ⚠️ 架构 v2 新增：全链（banana_pcb→电源板→HAT→总线）**目前无任何过流保护**，建议 banana_pcb 出线串 5A 保险 |
| [x] | 电池盒 | banana_pcb 取电方案配套；触点形式待登记 |
| [x] | 直流稳压电源 DLX-30V10AMF | 台架供电/实测（30V/10A，限流保护） |

## 线材与小件

| 状态 | 物料 | 说明 |
| :---: | :--- | :--- |
| [x] | 杜邦线 | IMU J2「直焊焊盘」路线材料；走此路线则无需另购座子+线 |
| [ ] | BM07B-SRSS-TB 座 + SH1.0 7P 线 | 仅当 J2 不走杜邦直焊路线时才需购 |
| [ ] | 飞特 5264 ↔ JST EH 3P 适配 | HAT 舵机座是 EH 3P，飞特原线是 5264 端子——**先试插再决定**（换 5264-3P 座或转接线），不预购 |
| [x] | 无头电子线 | banana_pcb 拆电池焊接出线备选；线径须按 3-5A 核对 |
| [x] | 电烙铁 + 焊锡/助焊剂 | IMU J2 焊接、banana_pcb 装配 |

## 工具（已到位）

万用表（10-09 到货）、直流电源、电烙铁——照片与用法存档见 [docs/photos/](./docs/photos/README.md)。

## 结构件

- [ ] 打印件清点：版本/材料/缺件登记。
- **C 线打印模型以上游独立仓库 [microduck-replica-cad](https://github.com/fanhao375/microduck-replica-cad) 为准**（本地未导入）；A 线的 `microduck-build-tutorial/microduck3D打印.3mf` 是 XL330 结构，**不适用 C 线**。
- C 线专属打印件：`banana_pcb_locker`（banana_pcb 到货后打）。

## 安全边界速记（C 线，按架构 v2）

- **全链吃电池直通电压**：舵机 ×15、IMU（板内 AP2210K-3.3 自降 3.3V，耐 13.2V）、HAT +BATT；5V 只在 HAT 板内（AP63205 2A，仅够主控）
- **全链无保险丝**：唯一兜底是电池自带保护板——banana_pcb 出线串 5A 保险（见供电表）
- **EH 座载流 3A** vs 整机常态 3-5A：总线**分两支**挂 CN11/CN12，单链 15 颗会让首座过全链电流
- **IMU 上电前台架验证一次**：限流 0.1A 从 J1-2 升到 8.4V，确认 J2-1 +3V3 稳定、U3 不烫（覆盖实物 LDO 与设计文件不符的残余风险）
- **HAT F1（21mA）在数据线上**，与舵机电源无关，不能当电源保护
- **电源板 MAX 6A** 天花板（若串入链路）；15 舵机同堵转远超，靠 robotd 力矩限幅兜底
- 2S 带载最低 6.6V：若电源板串入链路，其稳压口下限 ≈6.3V（实测）；直通口与拿掉电源板的直连方案无此限制

## A / B 线遗留资产（保留，不适用当前采购）

- A 训练基线与验收：[docs/a-training.md](./docs/a-training.md)；B 线训练（旧机环境）：[docs/b-training.md](./docs/b-training.md)、[.goal/PROJECT_KNOWLEDGE.md](./.goal/PROJECT_KNOWLEDGE.md)
- 回退 A 线时的采购清单：[docs/bom-route-a-20260928.md](./docs/bom-route-a-20260928.md)

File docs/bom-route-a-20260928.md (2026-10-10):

# 【存档】方案 A 采购清单（XL330 + OpenRB + Pi Zero）

> 2026-10-10 自根目录 BOM.md 原样存档（原文 2026-09-28 编写，未改动一字）。2026-10-09 路线定稿为 C 线（飞特）后，此清单不再对应现行采购；仅当回退 A 线时使用。其供电安全研究（XL330 3.7-6.0V 上限、OpenRB 板级电流限制）仍有效且值得读。现行清单见根 [BOM.md](../BOM.md)。

---

# BOM 采购清单

复刻一台 Microduck 的采购与准备清单，按到货周期分组，**不代表应无条件先下单**。价格、库存与交期请向当前渠道询价。先确认供电配电、结构装配和舵机配置路径，再采购高成本件；资料核对、软件检查和打印准备可并行进行。

采购表复选框跟踪采购/到位状态；软件资源表中的 `[x]` **只表示本地文件存在，不表示安装、功能或实机验证通过**。

## 下单前先确认

- [ ] 确定电池、匹配充电器、舵机受控供电、Pi 独立 5V 支路及保护/配电设计；核算线路额定并安排负载实测，不能只看电池标称电压。
- [ ] 核对打印工程与实际打印机、装配图、舵机配件包；确认结构件、螺丝、垫片和线材规格/数量。
- [ ] 选择舵机配置路径：OpenRB-150 的 `usb_to_dynamixel` 固件配合 Dynamixel Wizard 2.0，或可选 U2D2；确认供电、端口及配置后所需固件。
- [ ] 接受当前软件限制：现成策略可优先尝试、训练可后置，但模型/关节映射和缺失训练资源仍需处理，不能据文件存在保证能走路。

---

## 第一批：确认方案后优先询价的长交期核心件

| 状态 | 物料 | 数量 | 用途 | 备注 |
| :---: | :--- | :---: | :--- | :--- |
| [ ] | Dynamixel XL330-M288-T | 14 | 关节舵机 | 双腿 10 + 头颈 4。官方规格：18 g、20×34×26 mm、减速比 288.4:1、AS5601 非接触绝对磁编码器（12-bit，4096 pulse/rev）；工作电压 3.7～6.0V，推荐 5.0V。供电限制见下文。 |
| [ ] | ROBOTIS OpenRB-150 | 1 | 舵机总线控制板 | USB 接 Pi，4 个 TTL DYNAMIXEL 端口。**不是已验证的舵机稳压器**，也不能默认承担 14 个舵机的全部动力电流；端口总额定和跳线见下文。 |
| [ ] | XL330 备件（可选） | 预算允许时 1～2 | 替换/调试备用 | 按预算、交期与维修需求决定；没有损坏率统计，不作为必买件。 |

---

## 第二批：常规物料（规格确定后采购）

| 状态 | 物料 | 数量 | 用途 | 备注 |
| :---: | :--- | :---: | :--- | :--- |
| [ ] | Raspberry Pi Zero 2 W | 1 | 主控 | 控制程序、Wi-Fi/SSH、蓝牙手柄；仅支持 2.4GHz Wi-Fi。 |
| [ ] | microSD 卡 16GB+ | 1 | 系统盘 | 16GB+ 是上游建议；容量/质量需满足镜像与使用需求。首启自动扩容仅为上游说明，本轮未刷镜像验证。 |
| [ ] | BNO08x IMU 模块 | 1 | 姿态感知 | BNO080/085/086 只是候选；逐型号核对 **3.3V 逻辑兼容性**、模块供电、I2C 地址/上拉及软件支持。不同品牌模块不是无条件三选一、直接插接。 |
| [ ] | **电池及舵机稳压/配电方案（待选型）** | 1 套 | 动力供电 | 建议按舵机端受控 5.0V 设计，全工况保持 3.7～6.0V；需评估容量、动态响应、启动峰值、压降与温升。详见下方安全约束。 |
| [ ] | **匹配充电器** | 1 | 电池充电 | 匹配电池化学体系、串数、电压、电流和接头；电池断开控制器后充电。 |
| [ ] | Pi 稳定 5V 独立供电支路 | 1 套 | 主控供电 | 可以与舵机共用电池，**不要求两块电池，但需分支供电并共地**。输入低于 5V 或跨越 5V 时需相应升压/升降压，不能一概用普通降压模块。 |
| [ ] | 电源保护/配电器件、动力开关 | 按设计 | 保护与动力切断 | 按各段实际电流、峰值、线径和接头额定选型；包括设计所需的保险/过流、反接等保护，不以软件 Shutdown 替代硬件保护。 |
| [ ] | Dynamixel 3-pin 预制线材 | 按装配 | TTL 总线/供电连接 | 核对型号、针序、极性、长度和载流能力。可按右腿、左腿、头颈布线；三路不等于独立供电或各有独立额定。 |
| [ ] | 额外分线板（可选） | 按布线 | 总线连接 | OpenRB 已有 4 个 TTL 口，是否加分线板由布线与配电设计决定；不能因分线增加而提高板端额定。 |
| [ ] | M2 / M2.5 自攻螺丝 | 待核规格/数量 | 舵机与结构件固定 | 上游英语 BOM 有此类别；长度、头型、适用孔位及配件包内容须按实际装配核对，不把全体螺丝当成同一型号。 |
| [ ] | POM 垫片 / 钢垫片 | 待核规格/数量 | 支撑/间隔 | 上游英语 BOM 有此类别；内外径、厚度、材质与位置须核对装配图、打印件和配件包。 |
| [ ] | 匹配端子的预制电源线（含所需 JST-EH） | 按设计 | 电源连接 | 上游英语 BOM 列有 JST-EH，但不能据此推定所有接口型号；优先合格预制线，逐接口核针序、极性与载流。 |
| [ ] | 压线钳、端子及焊接工具（DIY 可选） | 按制作需要 | 自制/修整线束 | 工具与端子匹配；购买预制线时不必一律配压线钳。 |
| [ ] | 热缩管、绝缘材料、应力固定件 | 按需 | 绝缘与线束固定 | 热熔胶可作辅助固定，**不能替代合格压接/焊接、绝缘和应力固定**。 |

### ⚠️ 供电与配电：以下条件未确认前不要接舵机动力

**舵机端电压，而非电池标签，才是约束。** XL330-M288 官方工作范围为 **3.7～6.0V，推荐 5.0V**。设计须覆盖满电、低电、启动、负载变化和瞬态，保证舵机端全工况处于范围内；“成品”或“标称 6V”都不能证明满电及动态电压合格。

- 常见 2S Li-ion/18650 满电 **8.4V**、2S LiFePO4 满电约 **7.2～7.3V**，**不能直接接 XL330**；经合规降压、保护与配电设计后，可作为电源候选，而不是笼统禁用这类电池。
- 4×AA/AAA NiMH 也不能直接认定合适：满电/低电电压、内阻、输出电流、重量和续航均待评估。不据电压差异推断作者禁止自制电池的动机。
- 官方堵转参数：**5V 时 0.52 N·m / 1.47A；6V 时 0.60 N·m / 1.74A**。这些是堵转工况，**不是持续额定能力，也不等于整机常态电流**；不能用 `14 × 1.74A` 直接定额推荐整机电源。电池/稳压器容量与动态响应、启动峰值、线路压降及温升须按实际工况测量验证。
- Pi 用稳定 5V 独立支路，与舵机/控制器共地；避免未经设计将 USB 与其他正电源轨并联。不要把 Pi 的 USB 数据连接当作 14 个舵机的动态供电路径。

**OpenRB-150 需单独核对，不可由板输入范围推导舵机可承受电压：**

- 官方板输入为 **USB 5V、VIN 3.7～12.6V**；这不意味着板会自动为 XL330 稳压，更不允许向舵机施加超过 6.0V 的电压。
- 官方 **DYNAMIXEL PORTs 额定合计 3,000mA**，不是每口 3A，也不是自动限流/切断阈值。不能默认 14 个舵机的电流全部经过板；若实测负载超过板额定，须另设计并验证独立动力配电与保护。
- USB 路径有 **500mA 保险丝**，不能用 Pi USB 给 14 个舵机动态供电。板载 **5V 引脚新版额定 150mA、旧版 300mA**，不能用于给 Pi 供电。
- 采用 Terminal VIN 供电时，**先断开电池和 USB 等全部电源，再按官方图核对 VIN(DXL) 跳线**；本轮未验证实物默认跳线。须同时明确 USB 数据连接时的供电选择与正电源轨关系。

**软件电压参数不构成实物供电证据。** `microduck-build-tutorial/microduck/src/constants.py` 中 `BAM_VIN = 7.5` **高于** 6.0V 上限，而 `BAM_VIN_MIN = 6.0` **等于**上限，不是两个都高于。本轮不改代码参数；安全供电下的力矩、模型与行走性能匹配仍待验证。

---

## 第三批：配置与调试辅助（可借用或按需采购）

| 状态 | 物料 | 数量 | 用途 | 备注 |
| :---: | :--- | :---: | :--- | :--- |
| [x] | 万用表 | 1 | 上电前测极性/电压 | 2026-10-09 到货；万用表不能单独证明瞬态电压、峰值电流和温升合格，负载验证需合适测量手段。 |
| [ ] | HDMI 显示器 + mini HDMI 线/转接 + USB 键盘 | 各 1 或借用 | 首启/网络恢复 | Pi Zero 使用 mini HDMI 视频接口；保留此备用配置路径，不因计划编辑 `network-config` 就省略恢复手段。 |
| [ ] | Pi Zero microUSB OTG 数据口 → OpenRB USB-C 数据线/转接组合 | 1 套 | Pi 与 OpenRB 通信 | 必须支持 OTG/数据，不能是纯充电线；区分 Pi 的 **USB 数据口**与 **PWR IN 电源口**。键盘若同时使用，另按需配合适 OTG 扩展。 |
| [ ] | Linux 可用手柄（可选） | 1 | 无头模式操控 | 上游代码使用固定 Xbox 映射，注释仅记录部分按钮验证；Switch Pro 等须验证驱动、按键/轴映射，不是标准 HID 就一定兼容。可先评估 SSH 键盘控制路径。 |
| [ ] | Dynamixel U2D2（可选） | 1 或借用 | 便利的配置接口 | **不是设 ID 必需工具**；OpenRB 官方 `usb_to_dynamixel` sketch 可配合 Wizard 2.0。 |
| [ ] | U2D2 Power Hub（可选） | 按供电方案 | 配置时的电源接入 | Power Hub 与供电接入可有合规替代，不是 U2D2 绝对配套必买件；接口工具本身不等于已解决舵机供电。 |
| [ ] | 安全支架/悬吊防跌装置 | 1 套或自备 | 首次上电与动作调试 | 防跌并保持关节周围无人手/杂物，动力切断开关应易于触及。 |

> **`network-config` 的适用边界：**只针对具备相应首启配置机制的上游镜像，在**首次启动前**按上游方法处理；不是所有 Raspberry Pi OS 都支持的通用能力。本轮未下载、刷写或启动镜像，也未验证首启扩容和联网，键盘/显示器仍是备用路径。

---

## 结构件：3D 打印与装配核对

| 状态 | 项目 | 说明 |
| :---: | :--- | :--- |
| [ ] | 检查并切片 `microduck-build-tutorial/microduck3D打印.3mf` | 文件 **5,298,732 bytes**；Bambu Studio 工程，记录版本 **02.07.01.62**，配置 **P1S / 0.4mm 喷嘴 / PLA / 0.2mm 层高**。 |
| [ ] | 确认实际打印条件 | 其他机型/喷嘴须核验并重新切片；即使同为 Bambu，也不能无条件复用工程参数。核对打印机、材料、支撑、摆放和切片预览，或向代打印服务说明这些条件。 |
| [ ] | 核对零件和试装 | 不保证工程包含完整装配所需的全部零件、数量或正确尺寸；结合装配资料确认孔位、间隙、固定件和配件包，必要时先试打关键件。 |

当前上游目录缺少 `microduck/cad/`。模型目录 `microduck/src/model/mjcf/assets/` 中的 **10 个 SCAD 文件是 STL 背景引用加简单几何体，并非完整参数化 CAD**，不能据此承诺可全面修改结构尺寸。

缺失资源并非同一次删除：2026-09-11 的三次独立提交分别删除了 `robot`（`34656ce`）、`cad`（`570e0c2`）和 `docs`（`4967821`）。需要 CAD/训练模型时，可先检查历史快照 [`9a11a406a73c8d809daf6de939ef4df3f19f1656`](https://github.com/AI-FanGe/Microduck-build-tutorial/tree/9a11a406a73c8d809daf6de939ef4df3f19f1656) 下的 `microduck/cad` 与 `mjlab_microduck/src/mjlab_microduck/robot`，作为恢复候选；**恢复后仍须验证与当前代码、模型和硬件的兼容性**，并非只有向作者索取或重建这一条路径。本轮未恢复任何上游文件。

---

## 软件资源：本地已有文件与外部下载分开核对

### 本地已有（`[x]` 仅表示文件存在）

| 状态 | 资源 | 位置 / 限制 |
| :---: | :--- | :--- |
| [x] | 行走策略 `walk.onnx` | `microduck-build-tutorial/microduck/src/agents/walk.onnx`，**773,115 bytes**。可优先尝试现成策略、将训练后置；未验证模型加载、实机动作或行走能力。 |
| [x] | 训练权重 `velocity.pt` | `microduck-build-tutorial/mjlab_microduck/src/mjlab_microduck/agents/velocity.pt`，**4,887,111 bytes**。权重存在不代表训练环境或所需资源完整。 |
| [x] | IMU 方向检查/采样 UI | `microduck-build-tutorial/bno08x_calibrate_ui.py`：在 **Ubuntu PC 上运行 Tkinter UI，经 SSH** 访问 Pi；不是自动保存标定的工具。`--mount-quat` 默认值与部署配置不同，使用前须按实际安装方向匹配。 |
| [x] | IMU MuJoCo 方向查看工具 | `microduck-build-tutorial/scripts/imu_mujoco_orientation_viewer.py`；默认模型路径位于当前缺失的训练 `robot` 目录，不能按默认路径直接认为可用。 |
| [x] | 部署目录中的 MJCF / URDF 文件 | `microduck-build-tutorial/microduck/src/model/`；部署 MJCF 有 **19 个 motor**，与当前 14 关节配置不匹配，不能直接用于当前配置的仿真。 |

训练目录 `mjlab_microduck/src/mjlab_microduck/robot` 当前缺失。训练和仿真须先恢复/补齐匹配资源、核对关节与执行器映射和环境依赖；现成模型的存在不消除这些限制，也不构成全项目可用的证明。

### 外部资源（本轮未下载/刷机）

| 状态 | 资源 | 来源 / 元数据 |
| :---: | :--- | :--- |
| [ ] | 预编译树莓派镜像 `microduck.img.xz` | 上游 Release [`image.v1`](https://github.com/AI-FanGe/Microduck-build-tutorial/releases/tag/image.v1)，发布于 **2026-09-05**；[下载镜像](https://github.com/AI-FanGe/Microduck-build-tutorial/releases/download/image.v1/microduck.img.xz)，压缩文件 **768,792,340 bytes**。下载后核验 SHA256，再安排刷写与首启测试。 |

上游 Release 提供的 SHA256（对应 `microduck.img.xz`；**不是本轮下载文件后的实算结果**）：

```text
096885dc32fb5b1db2ad69ba6bea868d8ab988f2b47c0d884eb63ba0dfdcb5c4
```

---

## 装配与首次通电检查表

- [ ] **强烈建议装配前逐个连接舵机并设置唯一 ID**，按[上游 README](./microduck-build-tutorial/README.md) 的「舵机 ID」表与当前代码映射核对。装后如可单独连接舵机，或现有 ID 已唯一，仍可修改，不一定需要拆机。
- [ ] 确认配置工具与供电：OpenRB 的 `usb_to_dynamixel` sketch 是官方出厂固件，但实物仍须检查；配合 **Dynamixel Wizard 2.0，最高 1Mbps**。核对串口、跳线、电压与连接，配置后确认/切换到部署所需固件。
- [ ] 修改 ID 等 EEPROM 项目前使 **`Torque Enable = 0`**。协议 2.0、1Mbps、Return Delay Time 0、PWM Slope 255 是上游参考设置，须核对当前舵机/板端固件支持及部署要求，不盲目套用。
- [ ] **保留 Input Voltage Shutdown 等保护**；异常停机先检查电源、压降和接线，不把取消电压保护作为默认步骤。控制表电压阈值与工作范围不是一回事：Max Voltage Limit 寄存器默认 7.0V **不构成超过官方 6.0V 工作上限的依据**，也不代表保护会覆盖所有不安全电压。
- [ ] 调整供电、线材或跳线前，**断开电池、USB 等全部电源**；按官方图检查 VIN(DXL) 跳线与供电选择，防止未经设计的正电源轨并联。
- [ ] 上电前测极性、电压与短路风险，核对线径/开关/接头/保护额定；随后验证启动、动态负载、压降与温升，未证明合格前不进行自由行走测试。
- [ ] 首次动作在支架/悬吊防跌条件下进行，避免夹手，确保可迅速切断动力。常规停机先关闭系统再断电；**冒烟、短路、失控或夹伤等紧急情况立即切断动力**，不等待正常关机。
- [ ] 电池断开控制器后，使用匹配充电器充电。

---

## 2026-09-28 核查范围与待验证项

本轮仅依据本地文件静态检查、已确认的上游 Release/历史信息及官方资料修订采购说明；**未安装依赖、下载/刷写镜像、运行机器人或进行电气/机械实测，不宣称全项目可用**。

官方资料：[XL330-M288 e-Manual](https://emanual.robotis.com/docs/en/dxl/x/xl330-m288/) · [OpenRB-150 e-Manual](https://emanual.robotis.com/docs/en/parts/controller/openrb-150/)。

待确认/实测：电池与充电器选型、稳压/独立配电及保护；OpenRB 实物版本/跳线/固件与 USB 供电选择；舵机端全工况电压、峰值电流、压降、温升与续航；打印件/紧固件装配；IMU/手柄/镜像首启兼容性；恢复资源后的仿真映射和安全供电下的实机行走性能。

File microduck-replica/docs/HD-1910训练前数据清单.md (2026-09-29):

# HD-1910 训练前数据清单 · 已填版

**简体中文**

> 算法侧给的采集清单（2026-09-11，单舵机版）—— 这份是**把仓库里已有的数全填上、标明出处**，剩下真要上台架的标 **待实测**。
> 算法拿到的不该是空表：几何、质量、惯量、关节、舵机规格、IMU 安装，仓库早就有。

**标记**：【MJCF】上游 `robot_walk.xml` · 【规格书】飞特《HD-1910-C001 串型规格书》A/0 · 【源码】上游 `duck-control/src/model.rs` · 【逆向】[硬件方案逆向](硬件方案逆向.md) · 【STL】仓库 STL 实量 · **待实测**

> ⚠️ **几何、质量、惯量全部是 XL330 版的仿真值。** 换飞特之后至少四处不一样：
>
> | | XL330 | HD-1910 | 影响 |
> |---|---|---|---|
> | 单只质量 | 18 g | **21 g** | 15 颗 +45 g，各刚体质心挪 |
> | 外形 | 20 × 34 × 26 | **34 × 20 × 23** | 薄 3 mm，压腿处结构件已改 |
> | 堵转力矩 @7.4V | 0.6 N·m | **1.47 N·m** | BAM 模型重新辨识 |
> | 减速比 / 回差 | 未公开 | **320:1 / ≤0.5°** | 摩擦、回差模型重测 |
>
> **装机后实称实量覆盖这里的数** —— 差多少就是重训的理由。

---

## 一、静态数据

### 1. 机器人几何 —— 零位姿态、躯干坐标系（X 前 · Y 左 · Z 上）、mm

| 项 | 值 | 出处 |
|---|---|---|
| **两髋中心距离** | 髋 **yaw** 轴距 **35.0**；髋 **pitch** 轴距 **85.0**（腿运动学用这个） | 【MJCF】正向运动学 |
| **左 / 右大腿**（髋 pitch → 膝） | **42.2** / **42.2** | 【MJCF】 |
| **左 / 右小腿**（膝 → 踝） | **49.4** / **49.4** | 【MJCF】 |
| 髋 yaw → roll / roll → pitch | 20.7 / 31.1 | 【MJCF】 |
| **脚底尺寸**（`sole_left`，打印件包围盒） | 长 **54.0** × 宽 **41.1** × 厚 **12.9** | 【STL】左右对称；实际接触面看 foot + sole 装配后的底面 |
| **躯干尺寸**（`01_躯干主体` 装配体包围盒） | 长 **86.1** × 宽 **81.3** × 高 **64.0** | 【STL】含壳和髋部舵机 |
| 电池（NP-F550）位置 | X −55.3 … −16.7，Y ±10.3，Z −39.3 … +31.6 → 中心 **(−36, 0, −4)**，39 × 21 × 71 | 【逆向】MJCF 变换后实测 |
| `imu_to_dxl` 板位置 | 锁扣 `banana_pcb_locker` 处，X −32.3 … −28.5，Y ±27，Z +31.5 … +38.1，**竖装** | 【逆向】 |
| 主控 Radxa + 转接板 | *待装机后量* —— 不打 HAT 时位置自定 | **待实测** |

**关节轴位置与方向**（零位姿态、躯干系）：

| 关节 | 中心 X / Y / Z | 轴向 | 关节 | 中心 X / Y / Z | 轴向 |
|---|---|---|---|---|---|
| `left_hip_yaw` | 6.0 / 17.5 / −5.0 | −Z | `right_hip_yaw` | 6.0 / −17.5 / −5.0 | −Z |
| `left_hip_roll` | 22.5 / 17.5 / −17.5 | +X | `right_hip_roll` | 22.5 / −17.5 / −17.5 | +X |
| `left_hip_pitch` | 4.0 / 42.5 / −17.5 | +Y | `right_hip_pitch` | 4.0 / −42.5 / −17.5 | −Y |
| `left_knee` | −31.8 / 38.5 / −39.5 | −Y | `right_knee` | −31.8 / −38.5 / −39.5 | +Y |
| `left_ankle` | −31.8 / 64.5 / −81.5 | +Y | `right_ankle` | −31.8 / −64.5 / −81.5 | −Y |
| `neck_pitch` | 26.0 / 14.5 / 32.4 | −Y | `head_yaw` | 26.0 / 0.0 / 101.1 | +Z |
| `head_pitch` | 26.0 / 14.5 / 82.4 | +Y | `head_roll` | 8.1 / 0.0 / 115.6 | −X |

左右腿 pitch / knee / ankle 的轴向**符号相反** —— 镜像装配，MJCF 里就这么定义的。实物 +5° 核对方向时对着这张表。

### 2. 质量、重心与惯量 —— 【MJCF】XL330 版仿真值

| 刚体 | 质量 g | 质心（躯干系 mm） | 对应算法清单里的 |
|---|---|---|---|
| `trunk_base` | **199.2** | −22.6 / 0.0 / 2.8 | 躯干 |
| `yaw2roll` ×2 | 23.0 | 7.0 / ±17.5 / −21.9 | 髋 yaw 件（含舵机） |
| `hip_l` ×2 | 6.2 | 14.2 / ±32.3 / −17.5 | 髋 roll 件 |
| `upper_leg_left/right` | **48.2** | −18.9 / ±56.0 / −24.3 | **大腿** |
| `leg` / `leg_2` | **21.6** | −31.8 / ±48.0 / −71.4 | **小腿** |
| `ankle_left/right` | **30.0** | −25.6 / ±48.8 / −95.2 | **脚** |
| `neck` | 36.8 | 26.0 / 0.3 / 57.4 | 头颈 ┐ |
| `neck_pitch` | 5.7 | 26.0 / 0.0 / 94.1 | 头颈 │ 合计 **279.9** |
| `yaw_roll_motion` | 48.6 | 25.8 / −5.0 / 118.9 | 头颈 │ |
| `jaw_soft` | 188.8 | 40.6 / 1.2 / 120.2 | 头颈 ┘（含头壳、摄像头、HAT 那颗 BMI088） |
| **整机** | **737.1** | | 与 [执行器选型](执行器选型.md) 的 737 g 一致 |
| 电池 NP-F550 | *待称*（典型 ~100 g；是否已含在 trunk_base 里**待核**） | | |

**转动惯量**（kg·m²，各刚体自身质心系，MJCF `fullinertia` 顺序 Ixx Iyy Izz Ixy Ixz Iyz）：

```
trunk_base       1.240e-4  1.459e-4  1.154e-4   7.2e-8  -2.07e-5   1.3e-7
upper_leg_left   1.688e-5  1.037e-5  1.983e-5  -4.42e-6  2.28e-7   3.89e-7
leg              5.251e-6  2.155e-6  4.339e-6   0        0         7.65e-7
ankle_left       5.915e-6  1.115e-5  7.740e-6  -2.05e-7  8.2e-8    5.7e-8
yaw2roll         4.196e-6  3.418e-6  2.327e-6   0        0        -5.1e-8
hip_l            8.606e-7  1.158e-6  6.516e-7   0        3.90e-7   0
neck             1.729e-5  3.127e-6  1.637e-5   0        0         0
neck_pitch       1.092e-6  9.669e-7  5.121e-7   0        0         0
yaw_roll_motion  6.979e-6  8.103e-6  9.579e-6   3.22e-7 -3.5e-8    3.43e-7
jaw_soft         3.208e-4  2.541e-4  1.499e-4  -6.3e-7   6.57e-6   4.18e-6
```

右侧刚体对称（Ixy、Iyz 变号）。**HD-1910 装机后**：按实称质量缩放，或用同事的 SolidWorks 装配体（[microduck-replica-cad](https://github.com/fanhao375/microduck-replica-cad)）重算质量属性。

### 3. 14 个策略关节标定

动作序号 = 策略 14 维输出的下标（【源码】`JOINT_NAMES` 顺序，嘴不在内）。默认站立角 = 【源码】`DEFAULT_POSITION`。安全极限 = 【MJCF】`range`。

| 序号 | 关节 | 舵机 ID | 正方向 | 编码器零位 | 软件偏置 | 默认站立角 | 机械最小 | 机械最大 | 安全最小 | 安全最大 |
|---:|---|---|---|---|---|---|---|---|---|---|
| 0 | `left_hip_yaw` | **20** | *待标（+5° 核对）* | 2048（中位校准后） | 0（校准后）／官方 `motor.rs` 待读 | **+0.0°** | *待测* | *待测* | -25° | 30° |
| 1 | `left_hip_roll` | **21** | *待标（+5° 核对）* | 2048（中位校准后） | 0（校准后）／官方 `motor.rs` 待读 | **-5.0°** | *待测* | *待测* | -22° | 22° |
| 2 | `left_hip_pitch` | **22** | *待标（+5° 核对）* | 2048（中位校准后） | 0（校准后）／官方 `motor.rs` 待读 | **-26.2°** | *待测* | *待测* | -90° | 90° |
| 3 | `left_knee` | **23** | *待标（+5° 核对）* | 2048（中位校准后） | 0（校准后）／官方 `motor.rs` 待读 | **-0.3°** | *待测* | *待测* | -90° | 90° |
| 4 | `left_ankle` | **24** | *待标（+5° 核对）* | 2048（中位校准后） | 0（校准后）／官方 `motor.rs` 待读 | **+26.0°** | *待测* | *待测* | -90° | 90° |
| 5 | `neck_pitch` | **30** | *待标（+5° 核对）* | 2048（中位校准后） | 0（校准后）／官方 `motor.rs` 待读 | **+20.0°** | *待测* | *待测* | -90° | 60° |
| 6 | `head_pitch` | **31** | *待标（+5° 核对）* | 2048（中位校准后） | 0（校准后）／官方 `motor.rs` 待读 | **+20.0°** | *待测* | *待测* | -90° | 90° |
| 7 | `head_yaw` | **32** | *待标（+5° 核对）* | 2048（中位校准后） | 0（校准后）／官方 `motor.rs` 待读 | **+0.0°** | *待测* | *待测* | -170° | 170° |
| 8 | `head_roll` | **33** | *待标（+5° 核对）* | 2048（中位校准后） | 0（校准后）／官方 `motor.rs` 待读 | **+0.0°** | *待测* | *待测* | -25° | 25° |
| 9 | `right_hip_yaw` | **10** | *待标（+5° 核对）* | 2048（中位校准后） | 0（校准后）／官方 `motor.rs` 待读 | **+0.0°** | *待测* | *待测* | -30° | 25° |
| 10 | `right_hip_roll` | **11** | *待标（+5° 核对）* | 2048（中位校准后） | 0（校准后）／官方 `motor.rs` 待读 | **+5.0°** | *待测* | *待测* | -22° | 22° |
| 11 | `right_hip_pitch` | **12** | *待标（+5° 核对）* | 2048（中位校准后） | 0（校准后）／官方 `motor.rs` 待读 | **+26.2°** | *待测* | *待测* | -90° | 90° |
| 12 | `right_knee` | **13** | *待标（+5° 核对）* | 2048（中位校准后） | 0（校准后）／官方 `motor.rs` 待读 | **+0.3°** | *待测* | *待测* | -90° | 90° |
| 13 | `right_ankle` | **14** | *待标（+5° 核对）* | 2048（中位校准后） | 0（校准后）／官方 `motor.rs` 待读 | **-26.0°** | *待测* | *待测* | -90° | 90° |

**零位定义**：机器人笔直站立（腿是直柱、脚平、颈竖直、头平视）= 所有关节 0 = 舵机 2048。站立角是从零位加的偏移，**不是零位**。标定步骤见 [调试记录 · 第 9 步](../调试记录.md)。

嘴（ID 34）不在策略里：闭 −5° / 开 +30°（【源码】`MOUTH_CLOSED / MOUTH_OPEN`）。

### 4. HD-1910 基础参数 —— 【规格书】A/0，7.4 V 档（括号内 6 V）

| 项 | 值 |
|---|---|
| 精确型号 | **HD-1910-C001**（机械图纸标 HD-1910M-C001，2026-09-02） |
| 工作电压 | **4 – 8.4 V** ⚠️ NP-F550 满电 8.4 V 正好顶格 |
| 编码器分辨率 | **4096** counts/rev（12 bit 磁编码，0.088°/step） |
| 减速比 | **320 : 1** |
| 齿轮虚位 | ≤ 0.5°（厂家值；实测回差见二·5） |
| 通信协议 | 飞特 SCS/STS 串行总线，半双工 TTL 单线，8N1，帧头 `FF FF` |
| 波特率 | **1,000,000** bps（出厂默认；范围 38400 – 1M） |
| 控制模式 | **模式 4「纯位置 PD（Sim2Real）」**（出厂默认）；另有 0 角度伺服 / 1 恒速 / 2 恒流 / 3 PWM（规格书写法；通用 STS 内存表是 2 PWM / 3 步进，以实机读出的底账为准） |
| P / I / D 增益 | 寄存器 **21 / 23 / 22**（STS 通用）。默认值 **待读舵机**；官方 XL330 固件 kp = 200，对标用 |
| 最大速度 | 空载 **113 RPM = 11.8 rad/s** @7.4V（92 RPM @6V）；固件限速寄存器 46（目标速度）**待读** |
| 最大 PWM / 输出 | 寄存器 16「最大力矩」，0.1% 单位，默认 1000 = 100% **待读** |
| 最大电流 | 过流保护**默认关**，阈值默认 0.5 A / 2 s 可设；堵转 **2.0 A** @7.4V（1.6 A @6V）；额定 900 mA（690 mA） |
| Kt | 7.5 kg·cm/A（0.74 N·m/A） |
| 堵转力矩 | **15 kg·cm = 1.47 N·m** @7.4V（12 kg·cm @6V）；额定 3.7 kg·cm = 0.363 N·m |

**换算关系**（STS 系列内存表惯例；**HD-1910 逐项待核对规格书 7-x 或实读**）：

| 量 | 寄存器 | 换算 |
|---|---|---|
| 位置 | 56（当前）/ 42（目标） | rad = (raw − 2048) × 2π / 4096 |
| 速度 | 58（当前）/ 46（目标） | raw 为 steps/s，bit 15 为方向 → rad/s = raw × 2π / 4096 |
| 负载 | 60 | **无量纲**，0.1% 满力矩，bit 10 为方向（0–1000 → 0–100%） |
| 电流 | 69 | STS3215 为 **6.5 mA/unit**；**HD-1910 待核对** |
| 电压 | 62 | **0.1 V** /unit |
| 温度 | 63 | **1 ℃** /unit |
| 使能 | 40 | 1 开 0 关。内存表写着「写 128 = 中位校准」，但 **HD-1910（固件 3.46）实测不认**：2026-09-20 四轮 15 颗，解锁且扭矩关着写 128，偏移一个没变，舵机照样回成功。协议手册 4.9 的表里 HLS ≥3.43 也是「不支持写 128」。校零走 **0x0B 位置校准指令**（可带设定值），见 [servo-web](../tools/servo-web/) |

### 5. IMU 与足底

| 项 | 值 | 出处 |
|---|---|---|
| IMU 型号 | **LSM6DSV16X**（自制 `imu_to_dxl` 板，总线 ID 200，SFLP 硬件融合出四元数） | 【逆向】 |
| 安装方向 | 芯片 **+Z → 躯干 +X**，芯片 +Y → 躯干 +Y，芯片 −X → 躯干 +Z（绕 Y +90°）；板子竖装、元件面朝前 | 【逆向】上游 `SflpDecoder` mount |
| 安装位置 | MJCF `imu` site 躯干系 **(−21.0, 0.1, −14.7)**；实物在锁扣处 X ≈ −30，**装机后量** | 【MJCF】【逆向】 |
| 足底材料 | 打印件 `sole_left/right`，**材料按打印设置**（官方未指定；jaw / mouth 才是 TPU） | 【BOM】 |

---

## 二、动态数据 —— 全部 **待实测**，下面是台架和前置

### 1. BAM 单舵机摆锤辨识

四条轨迹（`sin_time_square` / `lift_and_drop` / `up_and_down` / `sin_sin`）是 [BAM](https://github.com/Rhoban/bam) 工具的标准激励。官方 XL330 用 BAM **M6** 模型，参数（【逆向】`microduck_constants.py`）：`kp_fw=200`、`vin_range=(6.5, 8.2)`、`vin_min=6.0`、`delay 3–6 步`。

**推荐组合**（按 2S 电池工作区间和官方口径）：

| | 值 | 理由 |
|---|---|---|
| 电压 ×3 | **6.6 / 7.4 / 8.2 V** | 电池放空 / 标称 / 满电（避开 8.4 顶格） |
| P ×4 | 舵机默认 / 100 / **200** / 300 | 200 对标官方 XL330 固件 |
| 摆长 ×2 | 0.10 / 0.15 m | 与腿长（42 + 49 mm）同量级 |
| 负载 ×3 | 0 / 0.05 / 0.10 kg | 单腿 ~100 g |
| 采样 | **50 Hz**（与控制周期一致），每段 20 s | |

**台架**：URT-2 + 可调电源（7.4 V 限 2 A）+ 摆杆 + 记录脚本。每个采样点记 `timestamp / goal_position / position / speed / load / input_volts / torque_enable / temperature` —— 寄存器 42 / 56 / 58 / 60 / 62 / 40 / 63，一次读 56–63 连读 8 字节。

### 2. 阶跃响应 · 3. 电压响应 · 4. 低速 · 5. 回差 · 6. 重复性

同一台架。**回差**要外部角度参考 —— 手机水平仪 app 贴摆杆上或量角器，编码器在齿轮输出侧，测不到自己的间隙。

**先做这两个，成本最低**：
- 阶跃 ±10° 重复 5 次 → 命令延迟、上升时间、超调
- 回差 ±1° / ±2° 重复 5 次 → 跟厂家 ≤0.5° 对一下

### 7. 控制与通信时序

要主控跑起来 —— 官方 `robotd` 每 5 分钟打一次汇总（达成频率、抖动、总线占用、错误计数），`bench_dynamixel_bus` 单独测总线。**不打 HAT 用第三方转接板时这是第一个要看的数**：错误率不为 0 就是转接板方向切换跟不上 1 Mbps。

### 8. 电源与压降

五工况表，需要分流器或钳形表在电池正极。**同时记电池端和舵机总线端**，差值就是走线 + 保险丝 + 连接器的压降。

### 9. IMU 数据

要 `imu_to_dxl` 板回来、固件写好。静止 60 s 读 ID 200 寄存器 124–136（gyro 3 × i16 + 四元数 3 × fp16）。方向检查按第 5 节那个 mount 四元数，前后左右各倾 10° 看投影重力的符号。

### 10. 足底摩擦

**现在就能做** —— 打印的脚已经在手：倾斜平面法，脚放地板上慢慢抬，滑动瞬间量角，μ ≈ tan θ。木地板 / 瓷砖 / 地毯各 5 次。

---

**改动记录**：2026-09-12 首版，从算法侧空表填起。装机实测后逐项覆盖，覆盖时把【MJCF】改成【实测】并记日期。

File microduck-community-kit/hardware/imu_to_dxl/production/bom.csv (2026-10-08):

Designator | Footprint | Quantity | Value | LCSC Part #
C1 | C0402 | 1 | 100p | C106200
C10, C11, C17 | C0402 | 3 | 27pF/50V | C107002
C12, C13, C14, C15, C16, C18, C19, C2, C7, C8, C9 | C0402 | 11 | 100nF/16V | C1525
C20, C21 | C0402 | 2 | 1uF/10V | C106254
C22 | C0402 | 1 | 1nF/50V | C106205
C5 | C0603 | 1 | 22uF/6.3V | C59461
C6 | C0805 | 1 | 10uF/50V | C2932476
D1 | SMA_L4.4-W2.6-LS5.0-RD | 1 | SMAJ24A | C90510
D2 | SOD-323_L1.7-W1.3-LS2.5-BI | 1 | 3.3V ESD | C46551335
F1 | F0603 | 1 | PTC(40R) | C2687114
L1 | IND-SMD_L3.0-W3.0_SWPA3010S | 1 | 10uH/920mA | C45403
Q1 | SOT-23 | 1 | MMBT3906 | C727128
R1 | R0402 | 1 | 75K | C144737
R10, R11, R12, R13, R17, R18, R2, R21, R22, R23, R24, R25, R26 | R0402 | 13 | 51R | C137960
R14 | R0402 | 1 | 1K | C11702
R15, R16, R19, R27, R28, R30, R7, R8 | R0402 | 8 | 10K | C25744
R29 | R0402 | 1 | 20k | C25765
R3, R31 | R0402 | 2 | 100K | C25741
R32, R9 | R0402 | 2 | 0R | C60485
R4 | R0402 | 1 | 30K | C25776
R5 | R0603 | 1 | 51R | C2907181
R6 | R0402 | 1 | 24K | C138026
U1 | SOT-23-6_L2.9-W1.6-P0.95-LS2.8-BR | 1 | ETA2845S2G_C22362741 | C22362741
U2 | LQFP-48_L7.0-W7.0-P0.50-LS9.0-BL | 1 | GD32F303CCT6 | C116151
U3 | LGA-14_L3.0-W2.5-P0.50-BR | 1 | LSM6DSV16XTR | C5267406
U4 | SOT-23-5 | 1 | SN74LVC1G126DBVR | C46472327
U5 | SOT-23-5 | 1 | SN74LVC1G125DBV | C3040625
U6 | SOT-23-5_L3.0-W1.7-P0.95-LS2.8-BR | 1 | ME6211C18M5G-N | C236671
X1 | CRYSTAL-SMD_4P-L3.2-W2.5-BL | 1 | XL2EL89CSI-111YLC-12M | C5280576

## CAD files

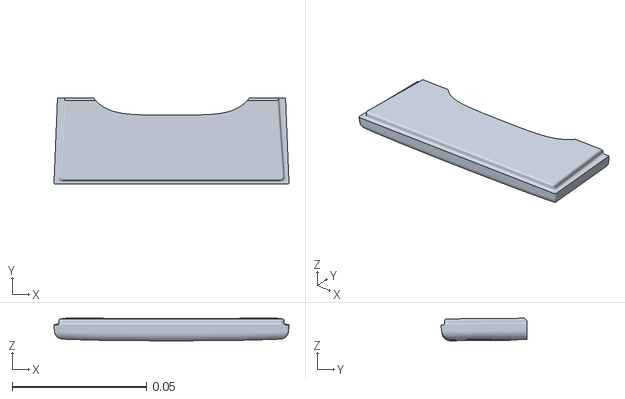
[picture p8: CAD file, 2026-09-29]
local-changes/microduck-build-tutorial/mjlab_microduck/src/mjlab_microduck/robot/microduck/assets/jaw_soft.stl
0.0877 x 0.0322 x 0.00844

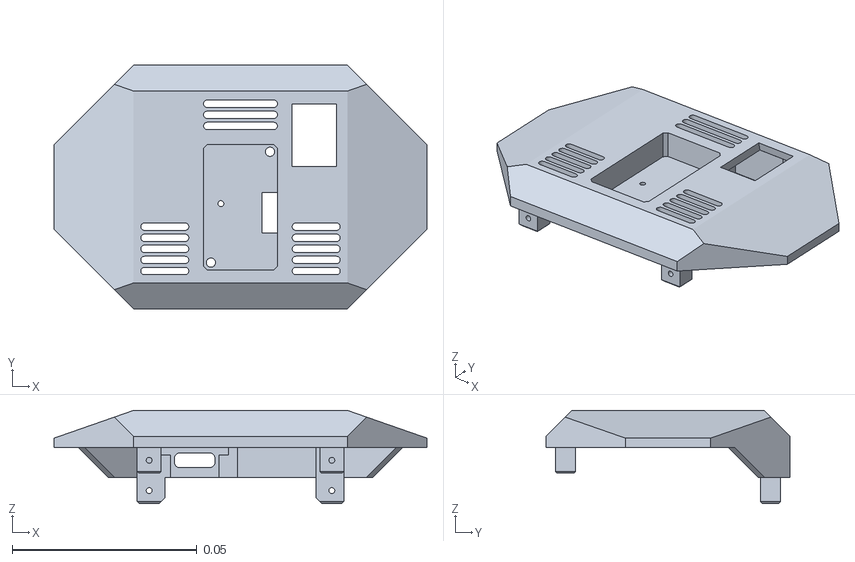
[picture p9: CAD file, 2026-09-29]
microduck-build-tutorial/microduck/src/model/mjcf/assets/trunk_top__configuration_right.stl
0.101 x 0.066 x 0.0252

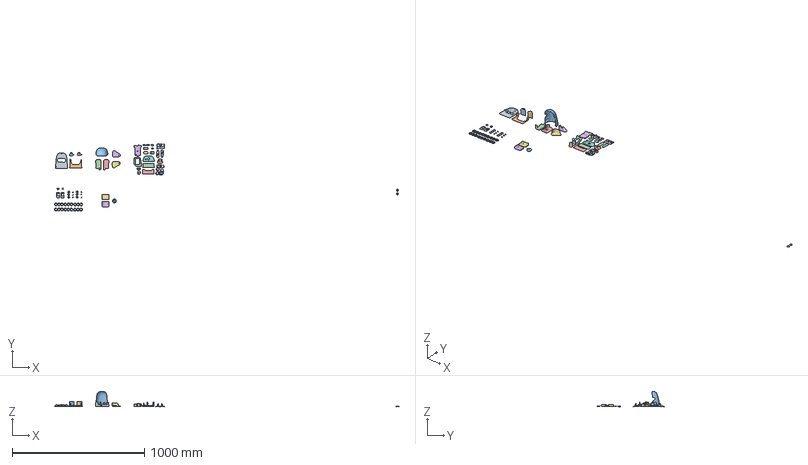
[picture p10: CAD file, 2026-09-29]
microduck-build-tutorial/microduck3D打印.3mf
2603.7 x 508.5 x 116.1 mm
3.obj
4.obj
5.obj
7.obj
8.obj
a.obj
b.obj x 2
d.obj
e.obj
f.obj
g.obj
h.obj
i.obj
j.obj
k.obj
l.obj
m.obj
n.obj
o.obj
p.obj
q.obj
111.obj
222.obj
333.obj
dfvdfb.obj x 2
ersgtbgertgestrg.obj x 18
idle_horn.stl x 8
idle_cap.stl x 6
rgbn.obj x 2
grbrgn.obj
thngthm.obj
dfbdfbbbbb1.obj
fgb.obj
gbgb.obj
ghmghmghmghm.obj

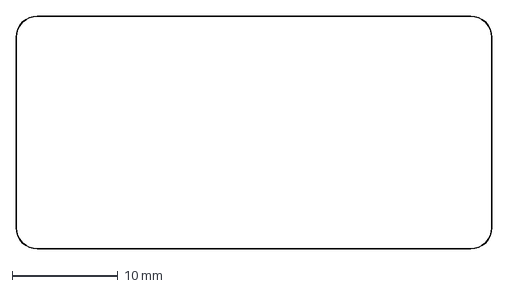
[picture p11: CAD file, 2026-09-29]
microduck-replica/hardware/imu_to_dxl/imu_to_dxl-板框-45x22-R2.dxf
45.0 x 22.0 mm

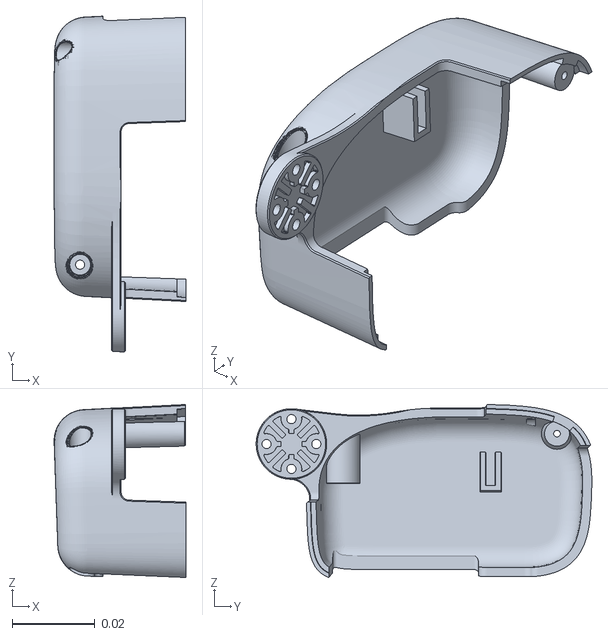
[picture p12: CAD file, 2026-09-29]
microduck-replica/software/training/src/mjlab_microduck/robot/microduck/assets/right_shell.stl
0.0318 x 0.0809 x 0.0417

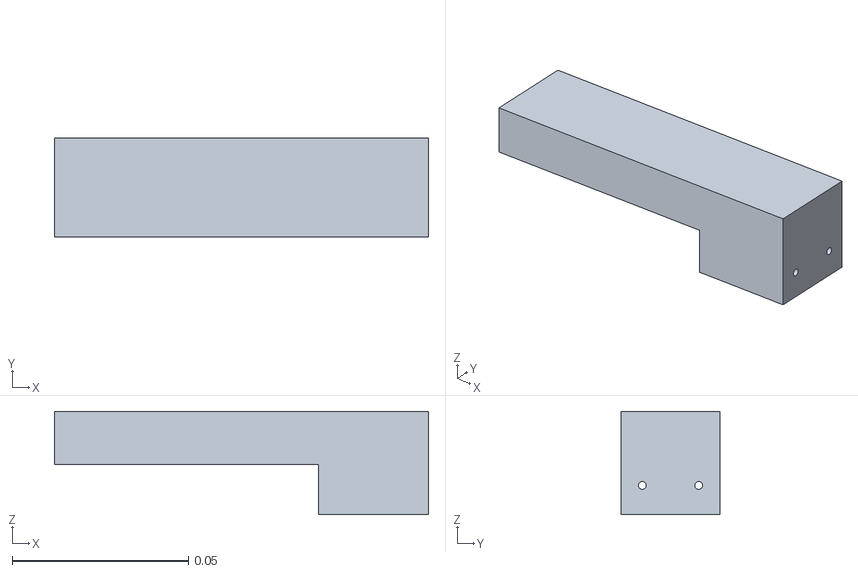
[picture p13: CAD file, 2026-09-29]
microduck-replica/software/training/src/mjlab_microduck/robot/xl330_test_bench/assets/bench_holder.stl
0.106 x 0.0282 x 0.0292

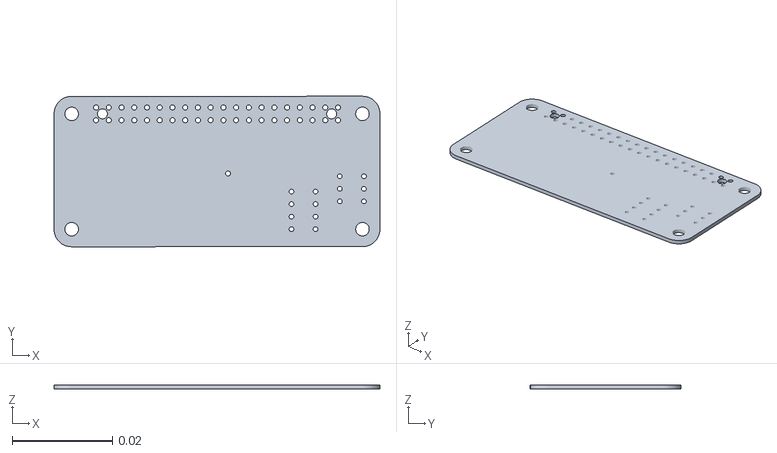
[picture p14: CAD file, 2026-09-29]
local-changes/microduck-build-tutorial/mjlab_microduck/src/mjlab_microduck/robot/microduck/assets/elec_rpi_robot_hat_pcb.stl
0.065 x 0.03 x 0.00084

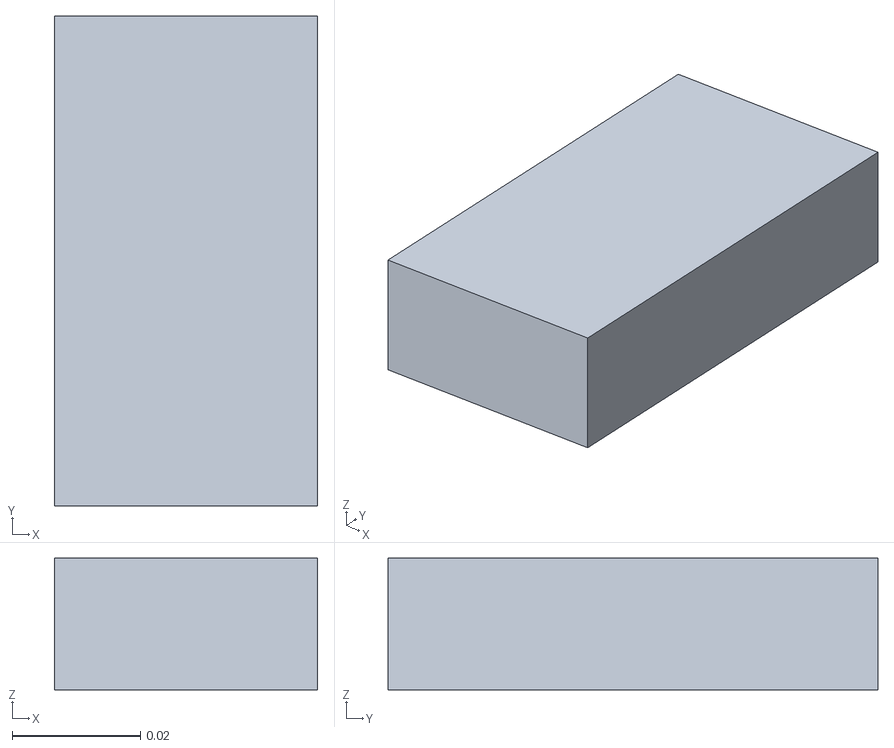
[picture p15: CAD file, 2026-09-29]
microduck-build-tutorial/microduck/src/model/mjcf/assets/battery.stl
0.041 x 0.0763 x 0.0205

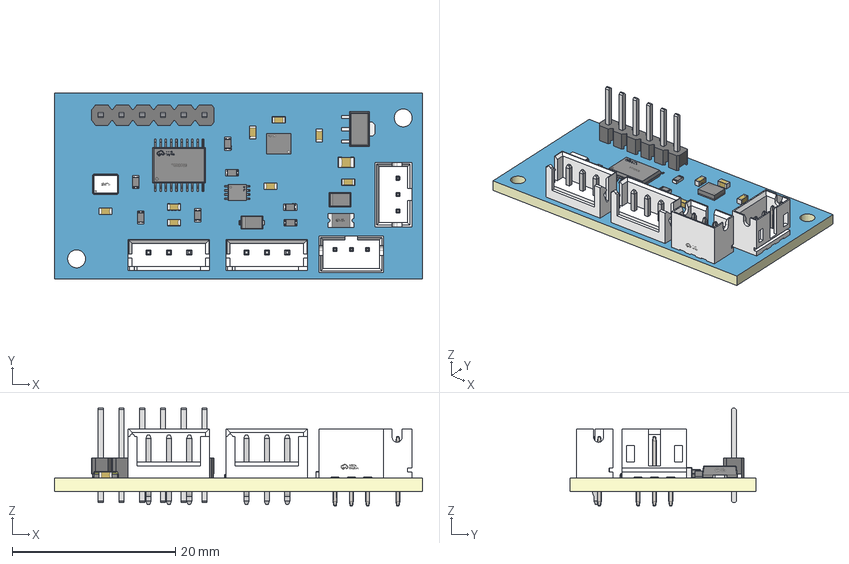
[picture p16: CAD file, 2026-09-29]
microduck-replica/hardware/imu_to_dxl/imu_to_dxl-PCB.step
45.1 x 22.7 x 12.0 mm
Board~ss66
TopCopper~ss66
BottomCopper~ss66
TopSilkscreen~ss66
BottomSilkscreen~ss66
TopFpcStiffener~ss66
BottomFpcStiffener~ss66
C0805~C0805_L2.0-W1.3-H1.3~nCY8
SOD-123FL_L2.7-W1.8-LS3.7-RD~SOD-123FL_L2.8-W1.8-H1.1-LS3.6~Ts2a
LGA-14_L3.0-W2.5-P0.50-BR~LGA-14_L3.0-W2.5-P0.50-BR~xgQh
CONN-TH_B3B-EH-A-LF-SN~CONN-TH_B3B-EH-A-LF-SN~hPIn x 2
R0603~R0603~2pOD x 7
HDR-TH_6P-P2.54-V-M~HDR-TH_6P-P2.54-M-LI-1X6P~mF3L
VSSOP-8_L2.3-W2.0-P0.50-LS3.1-BR~VSSOP-8_L2.3-W2.0-P0.50-LS3.1-BL~MIWO
SOD-123_L2.7-W1.6-LS3.7-RD~SOD-123_L2.7-W1.6-H1.4-LS3.7~0OJw
TSSOP-20_L6.5-W4.4-P0.65-LS6.4-BL~TSSOP-20_L6.5-W4.4-H1.0-LS6.4-P0.65~VWKP
C0603~C0603_L1.6-W0.8-H0.8~crEB x 8
CONN-TH_B3B-PH-K-S~CONN-TH_B3B-PH-K-S~Q7be x 2
SOT-89-3_L4.5-W2.5-P1.50-LS4.2-BR~SOT-89-3_L4.3-W2.5-H1.6-LS4.1-P1.50~uLfP
OSC-SMD_4P-L3.2-W2.5-BL_SIT8008BI~OSC-SMD_4P-L3.2-W2.5-H1.0~S9ms
F1206~F1206_L3.2-W1.7-H0.6~vEE0

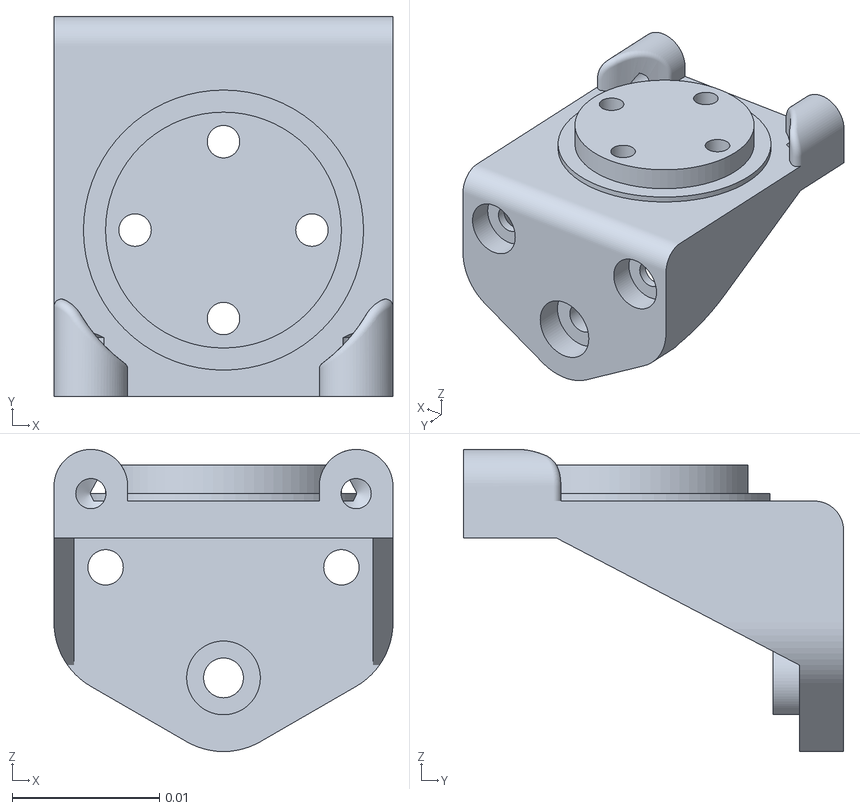
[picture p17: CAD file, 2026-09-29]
microduck-replica/software/training/src/mjlab_microduck/robot/microduck/assets/yaw2roll.stl
0.023 x 0.0258 x 0.0205

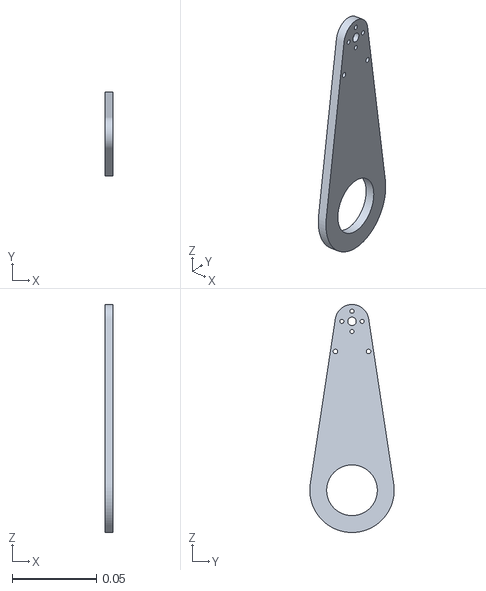
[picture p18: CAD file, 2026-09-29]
microduck-replica/software/training/src/mjlab_microduck/robot/xl330_test_bench/assets/arm.stl
0.005 x 0.05 x 0.135

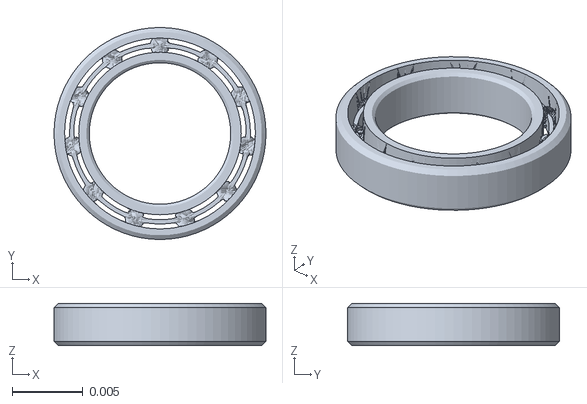
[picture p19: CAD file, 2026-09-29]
local-changes/microduck-build-tutorial/mjlab_microduck/src/mjlab_microduck/robot/microduck/assets/seeed_bearing__configuration_default.stl
0.015 x 0.015 x 0.003

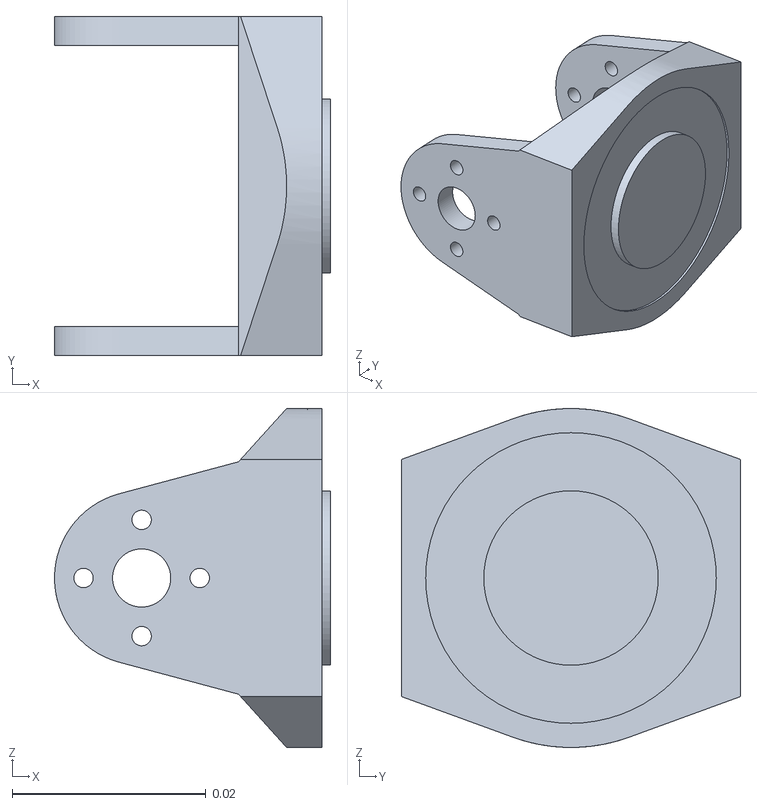
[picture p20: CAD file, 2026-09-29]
microduck-build-tutorial/microduck/src/model/mjcf/assets/shoulder.stl
0.0285 x 0.035 x 0.035

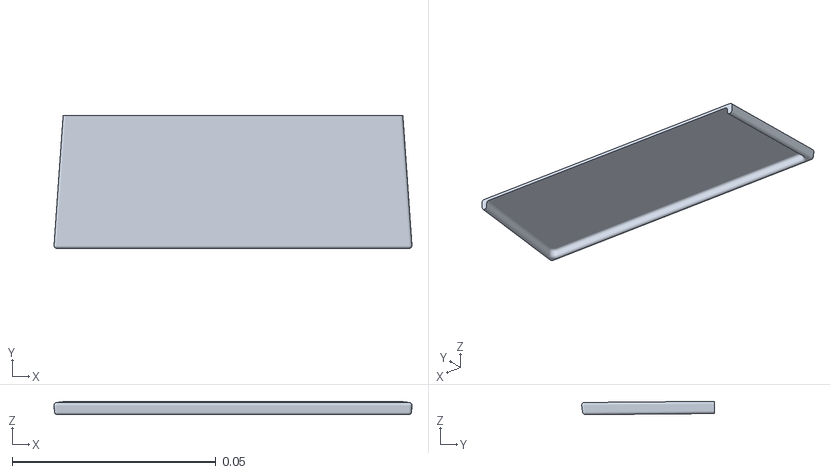
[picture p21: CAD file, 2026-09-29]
microduck-replica/software/training/src/mjlab_microduck/robot/microduck/assets/soft_mouth_top.stl
0.0878 x 0.0326 x 0.00328

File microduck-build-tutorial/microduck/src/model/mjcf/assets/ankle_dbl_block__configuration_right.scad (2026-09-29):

% scale(1000) import("ankle_dbl_block__configuration_right.stl");

// Append pure shapes (cube, cylinder and sphere), e.g:
// cube([10, 10, 10], center=true);
// cylinder(r=10, h=10, center=true);
// sphere(10);

translate([0, -12.75, 30.25])
cube([27, 50.5, 12.5], center=true);

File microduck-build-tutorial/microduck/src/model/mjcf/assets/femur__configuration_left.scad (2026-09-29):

% scale(1000) import("femur__configuration_left.stl");

// Append pure shapes (cube, cylinder and sphere), e.g:
// cube([10, 10, 10], center=true);
// cylinder(r=10, h=10, center=true);
// sphere(10);

translate([17.25-37, 18, 99.213])
cube([2.5, 18, 44.456], center=true);

translate([17.25-37, 11.818, 123.895])
rotate([45, 0, 0])
cube([2.5, 18, 24.941], center=true);

translate([17.25-37, 14.318, 77.031])
rotate([-45, 0, 0])
cube([2.5, 18, 17.87], center=true);

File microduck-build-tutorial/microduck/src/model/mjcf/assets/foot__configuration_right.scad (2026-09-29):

% scale(1000) import("foot.stl");

// Append pure shapes (cube, cylinder and sphere), e.g:
// cube([10, 10, 10], center=true);
// cylinder(r=10, h=10, center=true);
// sphere(10);

translate([0, 3.5, -12.25])
cube([45, 80, 2.5], center=true);

translate([0, 3.5, -12.25])
cube([35, 90, 2.5], center=true);

translate([17.5, -36.5, -12.25])
rotate([0, 0, 45])
cube([sqrt(50), sqrt(50), 2.5], center=true);

translate([-17.5, -36.5, -12.25])
rotate([0, 0, 45])
cube([sqrt(50), sqrt(50), 2.5], center=true);

translate([17.5, 43.5, -12.25])
rotate([0, 0, 45])
cube([sqrt(50), sqrt(50), 2.5], center=true);

translate([-17.5, 43.5, -12.25])
rotate([0, 0, 45])
cube([sqrt(50), sqrt(50), 2.5], center=true);

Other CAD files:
local-changes/microduck-build-tutorial/mjlab_microduck/src/mjlab_microduck/robot/microduck/assets/upper_leg_right.stl
microduck-build-tutorial/microduck/src/model/mjcf/assets/chest__configuration_right.stl
microduck-replica/software/training/src/mjlab_microduck/robot/microduck/assets/tire.stl
microduck-build-tutorial/microduck/src/model/mjcf/assets/femur__configuration_right.scad
local-changes/microduck-build-tutorial/mjlab_microduck/src/mjlab_microduck/robot/microduck/assets/ankle_left.stl
local-changes/microduck-build-tutorial/mjlab_microduck/src/mjlab_microduck/robot/microduck/assets/ankle_right.stl
local-changes/microduck-build-tutorial/mjlab_microduck/src/mjlab_microduck/robot/microduck/assets/banana_pcb_locker.stl
local-changes/microduck-build-tutorial/mjlab_microduck/src/mjlab_microduck/robot/microduck/assets/bearing_roll.stl
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

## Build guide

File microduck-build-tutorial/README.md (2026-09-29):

# Microduck

<p align="center">
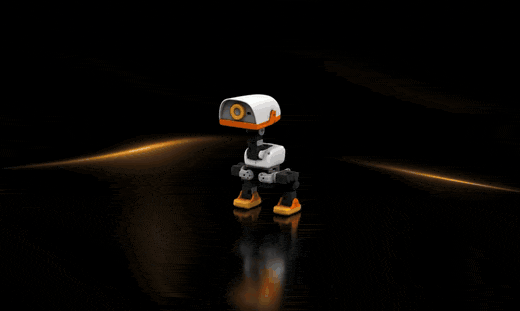
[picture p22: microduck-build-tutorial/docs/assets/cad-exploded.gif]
Microduck 结构爆炸图
  
</p>
<p align="center">
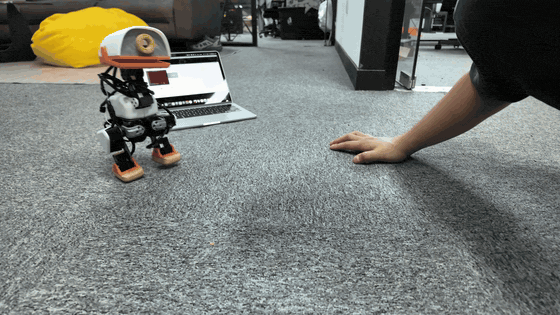
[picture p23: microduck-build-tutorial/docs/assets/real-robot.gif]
Microduck 人机互动
  
</p>
<p align="center">
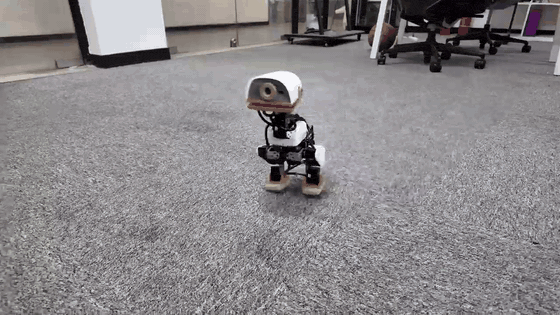
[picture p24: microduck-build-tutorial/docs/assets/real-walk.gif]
Microduck 实机行走
  
</p>

Microduck 是一个小型双足机器人项目，包含两部分：

- `microduck/`: Raspberry Pi Zero 2 W 上运行的部署代码，负责读取 IMU、读取手柄/键盘输入、驱动 Dynamixel 舵机，并加载 ONNX 行走策略。
- `mjlab_microduck/`: 基于 MuJoCo/MjLab 的强化学习训练环境，用来训练并导出 `walk.onnx`。

本 README 面向装机和第一次运行：准备硬件、接线、刷写 `microduck.img.xz`、初始化 Wi-Fi、SSH 登录、运行模型，以及后续更新代码。3D打印的文件在项目中。

视频教程：https://www.youtube.com/watch?v=Vep8AjoCnEM

## 致谢

感谢开源项目 [microban](https://github.com/Rhoban/microban) 和 [microduck](https://github.com/pollen-robotics/microduck)。本项目的机械结构、部署思路、仿真训练和实机行走流程都受益于这些开源工作。

## 项目状态

当前发布镜像已经内置：

- Raspberry Pi OS Lite 64-bit。
- 主机名 `microduck`。
- 默认用户 `user`。
- 部署目录 `~/microduck`。
- Python 虚拟环境 `~/microduck/.venv`。
- 行走模型 `~/microduck/src/agents/walk.onnx`。
- 无头手柄服务 `microduck-gamepad.service`，可开机后用手柄启动模型。

当前预构建镜像：

- [microduck.img.xz](https://github.com/AI-FanGe/Microduck-build-tutorial/releases/download/image.v1/microduck.img.xz)

## BOM

下面是组装一台 Microduck 的主要物料。价格会随地区、采购渠道和批量变化，仅用于估算。

| 类别 | 物料 | 数量 | 说明 |
| :--- | :--- | :---: | :--- |
| 控制板 | Raspberry Pi Zero 2 W | 1 | 运行控制程序、蓝牙手柄、Wi-Fi 和 SSH。 |
| 舵机控制板 | ROBOTIS OpenRB-150 | 1 | 通过 USB 连接 Raspberry Pi，负责和 XL330 舵机总线通信。代码会优先自动查找 `/dev/serial/by-id/usb-ROBOTIS_OpenRB-150_*`。 |
| 舵机 | Dynamixel XL330-M288-T | 14 | 当前行走代码使用 14 个舵机：双腿 10 个，头/颈 4 个。若安装嘴部舵机，可使用 ID 15，但当前行走模型不依赖它。 |
| 电池 | 成品 6V 可充电电池 | 1 | 当前硬件直接使用成品 6V 电池包供电，不使用两节 18650 自制电池组。请确认电池能提供足够瞬时电流。 |
| 开关 | 电源开关 | 1 | 控制机器人主电源。 |
| 存储 | 16GB 或更大 microSD 卡 | 1 | 推荐使用质量稳定的新卡。镜像刷写后首次启动会自动扩展分区。 |
| IMU | BNO080/BNO085/BNO086 模块 | 1 | 通过 I2C 读取姿态，代码会自动探测常见地址。 |
| 结构件 | 3D 打印件 | 1 套 | 使用 `microduck/cad/` 中的模型打印。推荐 PLA。 |
| 螺丝 | M2/M2.5 自攻螺丝 | 若干 | 舵机固定、舵盘固定、结构件连接。建议多备。 |
| 线材 | Dynamixel 3-pin 线| 若干 | 舵机串联、电源连接、分线。 |

## 舵机 ID

控制代码期望的 ID 映射如下。烧录镜像之前或第一次运行之前，应先用 Dynamixel Wizard 设置好每个舵机。

| ID | 名称 | 位置 |
| :---: | :--- | :--- |
| 1 | `right_ankle` | 右踝 |
| 2 | `right_knee` | 右膝 |
| 3 | `right_hip_pitch` | 右髋俯仰 |
| 4 | `right_hip_roll` | 右髋横滚 |
| 5 | `right_hip_yaw` | 右髋偏航 |
| 6 | `left_ankle` | 左踝 |
| 7 | `left_knee` | 左膝 |
| 8 | `left_hip_pitch` | 左髋俯仰 |
| 9 | `left_hip_roll` | 左髋横滚 |
| 10 | `left_hip_yaw` | 左髋偏航 |
| 11 | `head_pitch` | 头部俯仰 |
| 12 | `neck_pitch` | 颈部俯仰 |
| 13 | `head_yaw` | 头部偏航 |
| 14 | `head_roll` | 头部横滚 |
| 15 | `mouth` | 可选嘴部舵机，当前行走策略不使用 |

Dynamixel Wizard 推荐参数：

- Protocol: `2.0`
- Baud Rate: `1Mbps`
- Return Delay Time: `0`
- PWM Slope: `255`
- Shutdown: 去掉输入电压错误触发项，避免电池电压波动时误停

## 接线图

### 电源接线

电源链路如下：

```mermaid
flowchart LR
    BAT[成品 6V 可充电电池] --> SW[电源开关]
    SW --> OPENRB[OpenRB-150 电源输入]
    OPENRB --> BUS[XL330 舵机总线]
    PI[Raspberry Pi Zero 2 W] -->|USB 数据线| OPENRB
    BAT --> REG[5V 稳压/USB 供电]
    REG --> PI
```

检查要点：

- 上电前用万用表确认正负极。
- 当前硬件使用成品 6V 可充电电池，不需要自制 2S 电池组、BMS 和 2S 充电板。
- OpenRB-150 负责 XL330 舵机通信，Raspberry Pi 通过 USB 连接 OpenRB-150。
- Raspberry Pi 需要稳定 5V 供电；舵机/OpenRB-150 使用 6V 电池侧供电。两侧必须共地，具体以你的电源模块和 OpenRB-150 接法为准。
- 焊点需要热缩管或热熔胶绝缘，避免短路。

### 舵机总线

XL330 使用 3-pin 串联总线。OpenRB-150 接出后可通过分线分到左右腿和头部。

```mermaid
flowchart TD
    OPENRB[OpenRB-150 Dynamixel Port]
    OPENRB --> SPLIT[分线]
    SPLIT --> R5[右腿链: ID 5 -> 4 -> 3 -> 2 -> 1]
    SPLIT --> L10[左腿链: ID 10 -> 9 -> 8 -> 7 -> 6]
    SPLIT --> H12[头颈链: ID 12 -> 11 -> 13 -> 14]
```

注意：

- 舵机顺序可以按结构方便布线，但 ID 必须和上表一致。
- 如果总线上有通信错误，优先检查 OpenRB-150 是否枚举成功、电池电压、GND、线序和舵机 ID。
- 正常情况下代码会自动选择 OpenRB-150 的 USB 串口；如果没有找到，会回退到 `/dev/ttyACM0`、`/dev/serial0`、`/dev/ttyAMA0` 或 `/dev/ttyS0`。

### IMU 接线

BNO08x 模块走 I2C：

| IMU 引脚 | Raspberry Pi / Hat |
| :--- | :--- |
| `VIN` / `3V3` | 3.3V，按模块标识选择 |
| `GND` | GND |
| `SDA` | GPIO2 / I2C SDA |
| `SCL` | GPIO3 / I2C SCL |

软件默认使用 I2C bus `1`，会自动寻找 BNO08x 常见地址。安装方向由 `IMU_MOUNT_QUAT` 配置，已经和当前行走模型匹配。

## 使用 `microduck.img.xz`

### 1. 校验镜像

下载或拷贝镜像后，建议先校验：

```bash
sha256sum microduck.img.xz
```

应与发布页面或上文给出的 SHA256 一致。

### 2. 刷写 SD 卡

推荐使用 Raspberry Pi Imager：

1. 插入 microSD 卡。
2. 打开 Raspberry Pi Imager。
3. `Choose Device` 选择 `Raspberry Pi Zero 2 W`。
4. `Choose OS` 选择 `Use custom`，选中 `microduck.img.xz`。
5. `Choose Storage` 选择目标 microSD 卡。
6. 如果提示是否应用 OS customization，选择 `No`。
7. 点击 `Write`，等待写入和验证完成。

Linux 命令行也可以刷写，但要非常确认设备名：

```bash
lsblk
xzcat microduck.img.xz | sudo dd of=/dev/sdX bs=4M status=progress conv=fsync
```

把 `/dev/sdX` 换成你的 SD 卡设备，不要写成电脑硬盘。

### 3. 初始化 Wi-Fi

两种方法任选其一。Pi Zero 2 W 只支持 2.4GHz Wi-Fi，不要使用纯 5GHz 网络。

#### 方法 1：在电脑上编辑 SD 卡

刷写完成后，拔下再插回 SD 卡。Ubuntu 通常会挂载出两个分区：

- `bootfs`: 启动分区，可直接编辑 Wi-Fi 配置。
- `rootfs`: 系统根分区，一般不需要手动改。

编辑：

```bash
sudo nano /media/$USER/bootfs/network-config
```

内容类似：

```yaml
network:
  version: 2
  ethernets:
    eth0:
      dhcp4: true
      dhcp6: true
      optional: true
  wifis:
    wlan0:
      dhcp4: true
      regulatory-domain: "<YOUR_COUNTRY_CODE>"
      access-points:
        "<YOUR_WIFI_NAME>":
          password: "<YOUR_WIFI_PASSWORD>"
      optional: true
```

把三处占位符改掉：

- `<YOUR_COUNTRY_CODE>`: 两位国家/地区代码，例如 `CN`、`US`、`GB`、`FR`。
- `<YOUR_WIFI_NAME>`: Wi-Fi 名称。
- `<YOUR_WIFI_PASSWORD>`: Wi-Fi 密码。

可配置多个 Wi-Fi：

```yaml
      access-points:
        "HomeWifi":
          password: "home-password"
        "PhoneHotspot":
          password: "hotspot-password"
```

保存后安全弹出 SD 卡，插入机器人，打开电源。

#### 方法 2：插上 HDMI 和键盘，在 Pi 上用 nmcli

刷写完成后把 SD 卡插入 Pi，接上 mini HDMI 显示器和 USB 键盘（Zero 需要 OTG 转接头）。镜像是 Raspberry Pi OS Lite，没有桌面，开机后是终端登录。

第一次启动会扩展分区，等待 1 到 3 分钟，不要断电。出现登录提示后：

```text
用户名: user
密码:   password
```

输入密码时屏幕不会显示字符，直接回车。然后扫描并连接 Wi-Fi，设为开机自动连接：

```bash
nmcli device wifi list
sudo nmcli device wifi connect "你的WiFi名字" password "你的WiFi密码"
sudo nmcli con mod "你的WiFi名字" wifi.powersave disable
sudo nmcli con mod "你的WiFi名字" connection.autoconnect yes
```

检查是否连上、是否自动连接：

```bash
nmcli -t -f NAME,TYPE,AUTOCONNECT,DEVICE connection show
hostname -I
```

`AUTOCONNECT` 应为 `yes`，并且已经拿到 IP。之后每次开机都会自动连这个 Wi-Fi。

## 首次启动

第一次启动会做几件事：

- 扩展文件系统到整张 SD 卡。
- 重新生成 SSH host keys。
- 读取 `network-config` 并连接 Wi-Fi（方法 1）。若用方法 2，首次启动后再用 `nmcli` 配置。
- 启动后台手柄服务。

等待 1 到 3 分钟，然后在电脑上测试：

```bash
ping microduck.local
```

如果 `.local` 解析失败，到路由器后台查看 Pi 的 IP，然后用 IP 登录。

默认登录：

```bash
ssh user@microduck.local
```

默认密码：

```text
password
```

第一次登录后建议立刻改密码：

```bash
passwd
```

## 第一次运行模型

### SSH 模式

在电脑上远程登录 Pi。Windows 用 PowerShell，Linux / macOS 用终端：

```bash
ssh user@microduck.local
```

默认密码是 `password`。如果提示 `REMOTE HOST IDENTIFICATION HAS CHANGED`，先清掉旧记录再重连：

```bash
ssh-keygen -R microduck.local
```

登录成功后，把机器人放在稳定平面上或扶住，然后启动控制程序：

```bash
cd ~/microduck
PYTHONPATH=src .venv/bin/python src/main.py
```

启动后程序会：

1. 打开舵机扭矩。
2. 平滑回到 neutral pose。
3. 读取键盘或手柄输入。
4. 加载 `src/agents/walk.onnx` 行走策略。

键盘控制：

| 按键 | 功能 |
| :--- | :--- |
| `v` | 开启/关闭行走 |
| 方向键上/下 | 前进/后退 |
| 方向键左/右 | 左右转向 |
| `x` | 速度归零 |
| `i` | 显示/隐藏 IMU 信息 |
| `q` | 停止控制循环 |

### 远程 SSH 运行

电脑和机器人连同一个 2.4GHz Wi-Fi 后，在 Windows PowerShell 或 Linux / macOS 终端执行：

```bash
ssh user@microduck.local
```

登录后：

```bash
cd ~/microduck
PYTHONPATH=src .venv/bin/python src/main.py
```

停止：按 `q`。如果程序还在跑，另开一个 SSH 窗口：

```bash
ssh user@microduck.local
cd ~/microduck
PYTHONPATH=src .venv/bin/python src/stop.py
```

安全关机：

```bash
ssh user@microduck.local
sudo shutdown -h now
```

不要直接断电。先关机，等 10 到 15 秒，再关闭电源开关。

## 手柄模式

### 配对蓝牙手柄

SSH 到 Pi 后：

```bash
bluetoothctl
```

在 `bluetoothctl` 里执行：

```text
power on
agent on
scan on
pair XX:XX:XX:XX:XX:XX
trust XX:XX:XX:XX:XX:XX
connect XX:XX:XX:XX:XX:XX
scan off
quit
```

把 `XX:XX:XX:XX:XX:XX` 换成扫描到的手柄 MAC 地址。

### 无头运行

镜像里已经启用无头手柄服务。开机后：

| 操作 | 功能 |
| :--- | :--- |
| 按住 `START` 2 秒 | 启动控制循环 |
| `A` | 开启/关闭行走 |
| 左摇杆 | 前后/左右速度 |
| 右摇杆左右 | 原地或行进中转向 |
| `B` | 停止控制循环 |
| 同时按住左右扳机 2 秒 | 安全关机 |

手柄连接时，服务会关闭 Wi-Fi 以改善 2.4GHz 蓝牙稳定性。需要 SSH 时，先关闭手柄，Wi-Fi 会自动恢复。

## 常用命令

在开发电脑的 `microduck/` 目录下：

| 命令 | 说明 |
| :--- | :--- |
| `make sync` | 同步本地部署代码到 Pi 的 `~/microduck`。 |
| `make setup` | 同步代码并在 Pi 上执行 `uv sync --frozen`。改依赖后使用。 |
| `make run` | 同步并启动控制循环。 |
| `make stop` | 停止控制循环。 |
| `make shutdown` | 安全关闭 Pi。 |
| `make imu` | 查看 IMU/gyro 数据。 |
| `make voltage` | 查看舵机电压。 |
| `make voltage ID=2` | 查看指定舵机电压。 |
| `make gamepad-headless-enable` | 安装并启用无头手柄服务。 |
| `make gamepad-headless-disable` | 禁用无头手柄服务。 |

## 更新模型

训练仓 `mjlab_microduck/` 导出的 ONNX 模型应放到：

```bash
microduck/src/agents/walk.onnx
```

更新后同步：

```bash
cd microduck
make sync
```

下一次运行会加载新的 `walk.onnx`。

## 重新制作发布镜像

当 Pi 上的系统、依赖、服务和模型都确认可用后，可以把这张 SD 卡做成新的 `microduck.img.xz`。

推荐流程：

1. 先用当前 SD 卡实机测试 `make run` 或手柄无头运行。
2. 关机，把 SD 卡插回电脑。
3. 克隆整张卡到本地 `.img` 文件。
4. 只在镜像副本里清理敏感信息：
   - Wi-Fi 配置。
   - SSH host keys。
   - 用户 SSH key。
   - `/etc/machine-id`。
   - cloud-init 状态。
   - shell history、日志、apt 缓存。
5. 重置 `bootfs/network-config` 为占位模板。
6. 确认 `~/microduck/src/agents/walk.onnx`、`.venv`、`microduck-gamepad.service` 都存在。
7. 用 PiShrink 压缩生成 `microduck.img.xz`。
8. 计算 SHA256，并把校验值记录到 README 或 Release 说明里。

本仓库已有详细步骤：

```bash
microduck/docs/dev/clone_sd.md
```

## 目录结构

```text
.
├── README.md
├── microduck/
│   ├── Makefile
│   ├── src/
│   │   ├── main.py
│   │   ├── scheduler.py
│   │   ├── robot_controller.py
│   │   ├── imu_reader.py
│   │   ├── agents/walk.onnx
│   │   └── moves/walk.py
│   ├── systemd/
│   └── docs/
└── mjlab_microduck/
    ├── src/mjlab_microduck/
    └── logs/
```

## 故障排查

### 找不到 `microduck.local`

先等 1 到 3 分钟。仍找不到时：

- 确认 Wi-Fi 是 2.4GHz。
- 确认 `network-config` YAML 缩进没变（方法 1）。
- 若用方法 2，在 Pi 上执行 `nmcli device wifi list` 和 `hostname -I` 确认已连上 2.4GHz 并拿到 IP。
- 到路由器后台查 Pi 的 IP。
- 用 `ssh user@<IP>` 登录。

### SSH 提示 host key changed

发布镜像首次启动会重新生成 SSH host keys。如果同一台电脑以前连过另一张卡，清理本机记录：

```bash
ssh-keygen -R microduck.local
ssh-keygen -R <IP>
```

### 舵机不动或通信错误

检查：

- 电池电压是否正常。
- OpenRB-150、舵机总线和 Raspberry Pi 供电/GND 是否正确。
- 舵机 ID 是否符合上表。
- Dynamixel 波特率是否为 1Mbps。
- OpenRB-150 的 USB 串口是否能被识别。
- 线序、分线和插头方向是否正确。

### 手柄连接后 SSH 断开

这是无头模式的设计：手柄连接后会关闭 Wi-Fi，提升蓝牙稳定性。关闭手柄后 Wi-Fi 会恢复。

### 机器人一启动就容易倒

先手扶机器人运行，确认：

- 左右腿舵机 ID 没有装反。
- 膝盖 offset 与实际装配一致。
- IMU 安装方向正确。
- `walk.onnx` 是当前硬件对应的模型。

## 安全提示

- 第一次运行一定要扶住机器人。
- 不要在桌边或高处测试。
- 不要在电池低电压时长时间运行。
- 不要直接断电，先执行 `make shutdown` 或手柄安全关机。
- 充电和上电前检查短路、极性和焊点绝缘。

---

# Microduck (English)

<p align="center">
  Microduck exploded view
</p>
<p align="center">
  Microduck human-robot interaction
</p>
<p align="center">
  Microduck walking
</p>

Microduck is a compact biped robot project. This repository presents one practical hardware and software setup for running an ONNX reinforcement learning walking policy on real Dynamixel XL330 servos.

The project contains two main parts:

- `microduck/`: deployment code for the Raspberry Pi Zero 2 W. It reads the IMU, reads keyboard or gamepad commands, drives Dynamixel servos, and loads the ONNX walking policy.
- `mjlab_microduck/`: reinforcement learning training environment based on MuJoCo/MjLab. It is used to train and export `walk.onnx`.

This README covers the full first-time workflow: hardware, wiring, flashing `microduck.img.xz`, Wi-Fi setup, first SSH login, first run, day-to-day usage, and rebuilding a release image.

## Acknowledgements

Thanks to the open-source projects [microban](https://github.com/Rhoban/microban) and [microduck](https://github.com/pollen-robotics/microduck). This project benefits from their mechanical design, deployment ideas, simulation training work, and real-robot walking pipeline.

## Project Status

The current release image includes:

- Raspberry Pi OS Lite 64-bit.
- Hostname `microduck`.
- Default user `user`.
- Deployment directory `~/microduck`.
- Python virtual environment `~/microduck/.venv`.
- Walking model `~/microduck/src/agents/walk.onnx`.
- Headless gamepad service `microduck-gamepad.service`, so the walking controller can be started from a gamepad after boot.

Current prebuilt image:

- [microduck.img.xz](https://github.com/AI-FanGe/Microduck-build-tutorial/releases/download/image.v1/microduck.img.xz)

SHA256:

```text
096885dc32fb5b1db2ad69ba6bea868d8ab988f2b47c0d884eb63ba0dfdcb5c4
```

## BOM

The following is the main bill of materials for building one Microduck. Prices vary by region, supplier, and quantity, so treat them as estimates.

| Category | Part | Qty | Notes |
| :--- | :--- | :---: | :--- |
| Main controller | Raspberry Pi Zero 2 W | 1 | Runs the control program, Bluetooth gamepad, Wi-Fi, and SSH. |
| Servo controller | ROBOTIS OpenRB-150 | 1 | Connected to the Raspberry Pi over USB. It communicates with the XL330 servo bus. The code first looks for `/dev/serial/by-id/usb-ROBOTIS_OpenRB-150_*`. |
| Servos | Dynamixel XL330-M288-T | 14 | The current walking code uses 14 servos: 10 for the legs and 4 for the head/neck. An optional mouth servo can use ID 15, but the walking policy does not depend on it. |
| Battery | Ready-made 6V rechargeable battery | 1 | This hardware setup uses a ready-made 6V battery pack, not a custom two-cell pack. Make sure the battery can provide enough peak current. |
| Switch | Power switch | 1 | Main power switch for the robot. |
| Storage | 16GB or larger microSD card | 1 | Use a reliable new card. The image expands the filesystem on first boot. |
| IMU | BNO080/BNO085/BNO086 module | 1 | Read over I2C. The code auto-detects common BNO08x addresses. |
| Mechanical parts | 3D-printed parts | 1 set | Print from the models under `microduck/cad/`. PLA is recommended. |
| Screws | M2/M2.5 self-tapping screws | Several | Used for servo mounting, horn mounting, and structural assembly. Keep extras. |
| Bearings/shims | POM shims and steel shims | Several | Low-cost rotational support. |
| Cables | Dynamixel 3-pin cables, JST wires, power connectors | Several | Servo daisy chains, power wiring, and splitters. |
| Setup tools | Dynamixel U2D2 + U2D2 Power Hub | 1 set | Used to configure servo IDs, baud rate, and parameters. One set can be shared across multiple robots. |

Recommended extras:

- Spare XL330 servos, spare 6V battery, power wires, and Dynamixel cables.
- JST-EH terminals, crimping tool, heat-shrink tubing, and hot glue.
- A multimeter for checking polarity and battery voltage.

## Servo IDs

The deployment code expects the following ID mapping. Configure every servo with Dynamixel Wizard before the first run.

| ID | Name | Position |
| :---: | :--- | :--- |
| 1 | `right_ankle` | Right ankle |
| 2 | `right_knee` | Right knee |
| 3 | `right_hip_pitch` | Right hip pitch |
| 4 | `right_hip_roll` | Right hip roll |
| 5 | `right_hip_yaw` | Right hip yaw |
| 6 | `left_ankle` | Left ankle |
| 7 | `left_knee` | Left knee |
| 8 | `left_hip_pitch` | Left hip pitch |
| 9 | `left_hip_roll` | Left hip roll |
| 10 | `left_hip_yaw` | Left hip yaw |
| 11 | `head_pitch` | Head pitch |
| 12 | `neck_pitch` | Neck pitch |
| 13 | `head_yaw` | Head yaw |
| 14 | `head_roll` | Head roll |
| 15 | `mouth` | Optional mouth servo, not used by the current walking policy |

Recommended Dynamixel Wizard settings:

- Protocol: `2.0`
- Baud Rate: `1Mbps`
- Return Delay Time: `0`
- PWM Slope: `255`
- Shutdown: remove the input-voltage-error trigger to avoid unwanted shutdowns during battery voltage dips

## Wiring

### Power Wiring

The power path is:

```mermaid
flowchart LR
    BAT[Ready-made 6V rechargeable battery] --> SW[Power switch]
    SW --> OPENRB[OpenRB-150 power input]
    OPENRB --> BUS[XL330 servo bus]
    PI[Raspberry Pi Zero 2 W] -->|USB data cable| OPENRB
    BAT --> REG[5V regulator / USB power]
    REG --> PI
```

Checklist:

- Check polarity with a multimeter before powering on.
- This setup uses a ready-made 6V rechargeable battery. It does not require a custom two-cell battery pack, BMS, or 2S charger board.
- OpenRB-150 handles XL330 servo communication. The Raspberry Pi connects to it over USB.
- The Raspberry Pi needs stable 5V power. The servos/OpenRB-150 are powered from the 6V battery side. Grounds must be common. Follow your actual regulator and OpenRB-150 wiring.
- Insulate solder joints with heat-shrink tubing or hot glue to prevent shorts.

### Servo Bus

XL330 servos use a 3-pin daisy-chain bus. The OpenRB-150 output can be split into the right leg, left leg, and head/neck chains.

```mermaid
flowchart TD
    OPENRB[OpenRB-150 Dynamixel Port]
    OPENRB --> SPLIT[Splitter]
    SPLIT --> R5[Right leg chain: ID 5 -> 4 -> 3 -> 2 -> 1]
    SPLIT --> L10[Left leg chain: ID 10 -> 9 -> 8 -> 7 -> 6]
    SPLIT --> H12[Head/neck chain: ID 12 -> 11 -> 13 -> 14]
```

Notes:

- The physical cable order can follow the mechanical layout, but the servo IDs must match the table above.
- If the bus has communication errors, first check that the OpenRB-150 enumerates correctly, then check battery voltage, ground, cable order, and servo IDs.
- Normally the code automatically selects the OpenRB-150 USB serial port. If not found, it falls back to `/dev/ttyACM0`, `/dev/serial0`, `/dev/ttyAMA0`, or `/dev/ttyS0`.

### IMU Wiring

The BNO08x module uses I2C:

| IMU Pin | Raspberry Pi / Hat |
| :--- | :--- |
| `VIN` / `3V3` | 3.3V, depending on the module label |
| `GND` | GND |
| `SDA` | GPIO2 / I2C SDA |
| `SCL` | GPIO3 / I2C SCL |

The software uses I2C bus `1` by default and auto-detects common BNO08x addresses. The mounting orientation is configured by `IMU_MOUNT_QUAT`, which is already matched to the current walking model.

## Using `microduck.img.xz`

### 1. Verify the Image

After downloading or copying the image, verify it:

```bash
sha256sum microduck.img.xz
```

The result should match the SHA256 published with the image.

### 2. Flash the SD Card

Raspberry Pi Imager is recommended:

1. Insert the microSD card.
2. Open Raspberry Pi Imager.
3. Select `Choose Device` -> `Raspberry Pi Zero 2 W`.
4. Select `Choose OS` -> `Use custom`, then choose `microduck.img.xz`.
5. Select `Choose Storage`, then choose the target microSD card.
6. If asked whether to apply OS customization settings, choose `No`.
7. Click `Write` and wait for writing and verification to complete.

You can also flash from the Linux command line. Be very careful with the device name:

```bash
lsblk
xzcat microduck.img.xz | sudo dd of=/dev/sdX bs=4M status=progress conv=fsync
```

Replace `/dev/sdX` with your SD card device. Do not write to your computer's internal disk.

### 3. Initialize Wi-Fi

Use either method. The Raspberry Pi Zero 2 W only supports 2.4GHz Wi-Fi. Do not use a 5GHz-only network.

#### Method 1: Edit the SD card on a computer

After flashing, unplug and reinsert the SD card. Ubuntu usually mounts two partitions:

- `bootfs`: boot partition, where Wi-Fi can be configured.
- `rootfs`: root filesystem, usually no manual edits are needed.

Edit:

```bash
sudo nano /media/$USER/bootfs/network-config
```

The file looks like this:

```yaml
network:
  version: 2
  ethernets:
    eth0:
      dhcp4: true
      dhcp6: true
      optional: true
  wifis:
    wlan0:
      dhcp4: true
      regulatory-domain: "<YOUR_COUNTRY_CODE>"
      access-points:
        "<YOUR_WIFI_NAME>":
          password: "<YOUR_WIFI_PASSWORD>"
      optional: true
```

Replace:

- `<YOUR_COUNTRY_CODE>`: two-letter country code, such as `CN`, `US`, `GB`, or `FR`.
- `<YOUR_WIFI_NAME>`: Wi-Fi name.
- `<YOUR_WIFI_PASSWORD>`: Wi-Fi password.

Multiple Wi-Fi networks can be configured:

```yaml
      access-points:
        "HomeWifi":
          password: "home-password"
        "PhoneHotspot":
          password: "hotspot-password"
```

Save the file, safely eject the SD card, insert it into the robot, and power on.

#### Method 2: HDMI and keyboard, then nmcli on the Pi

After flashing, insert the SD card into the Pi and connect a mini HDMI display plus a USB keyboard (the Zero needs a USB OTG adapter). The image is Raspberry Pi OS Lite, so there is no desktop — only a terminal login.

The first boot expands the partition. Wait 1 to 3 minutes and do not power off. When the login prompt appears:

```text
username: user
password: password
```

The password is not echoed. Then scan, connect, and enable autoconnect:

```bash
nmcli device wifi list
sudo nmcli device wifi connect "YOUR_WIFI_NAME" password "YOUR_WIFI_PASSWORD"
sudo nmcli con mod "YOUR_WIFI_NAME" wifi.powersave disable
sudo nmcli con mod "YOUR_WIFI_NAME" connection.autoconnect yes
```

Check that it is connected and set to autoconnect:

```bash
nmcli -t -f NAME,TYPE,AUTOCONNECT,DEVICE connection show
hostname -I
```

`AUTOCONNECT` should be `yes`, and the Pi should have an IP address. After that, this Wi-Fi will connect automatically on every boot.

## First Boot

On first boot, the image will:

- Expand the filesystem to the full SD card.
- Regenerate SSH host keys.
- Read `network-config` and join Wi-Fi (method 1). If you use method 2, configure Wi-Fi with `nmcli` after the first boot.
- Start the background gamepad service.

Wait 1 to 3 minutes, then test from your computer:

```bash
ping microduck.local
```

If `.local` does not resolve, check your router's DHCP client list and use the Pi's IP address.

Default login:

```bash
ssh user@microduck.local
```

Default password:

```text
password
```

Change the password after the first login:

```bash
passwd
```

## First Run

### SSH Mode

Log in to the Pi from a computer. Use PowerShell on Windows, or a terminal on Linux / macOS:

```bash
ssh user@microduck.local
```

The default password is `password`. If SSH says `REMOTE HOST IDENTIFICATION HAS CHANGED`, clear the old host key and try again:

```bash
ssh-keygen -R microduck.local
```

After login, place the robot on a stable surface or hold it, then start the control program:

```bash
cd ~/microduck
PYTHONPATH=src .venv/bin/python src/main.py
```

On startup, the program will:

1. Enable servo torque.
2. Smoothly move to the neutral pose.
3. Read keyboard or gamepad input.
4. Load `src/agents/walk.onnx`.

Keyboard controls:

| Key | Action |
| :--- | :--- |
| `v` | Toggle walking |
| Up/down arrows | Forward/backward |
| Left/right arrows | Turn left/right |
| `x` | Zero velocity |
| `i` | Show/hide IMU status |
| `q` | Stop the control loop |

### Remote SSH

After the computer and the robot are on the same 2.4GHz Wi-Fi, run this in Windows PowerShell or a Linux / macOS terminal:

```bash
ssh user@microduck.local
```

Then:

```bash
cd ~/microduck
PYTHONPATH=src .venv/bin/python src/main.py
```

Stop with `q`. If the program is still running, open another SSH session:

```bash
ssh user@microduck.local
cd ~/microduck
PYTHONPATH=src .venv/bin/python src/stop.py
```

Safe shutdown:

```bash
ssh user@microduck.local
sudo shutdown -h now
```

Do not cut power directly. Shut the Pi down first, wait 10 to 15 seconds, then turn off the power switch.

## Gamepad Mode

### Pair a Bluetooth Gamepad

SSH into the Pi, then run:

```bash
bluetoothctl
```

Inside `bluetoothctl`:

```text
power on
agent on
scan on
pair XX:XX:XX:XX:XX:XX
trust XX:XX:XX:XX:XX:XX
connect XX:XX:XX:XX:XX:XX
scan off
quit
```

Replace `XX:XX:XX:XX:XX:XX` with the detected controller MAC address.

### Headless Operation

The image already enables the headless gamepad service. After boot:

| Action | Function |
| :--- | :--- |
| Hold `START` for 2 seconds | Start the control loop |
| `A` | Toggle walking |
| Left stick | Forward/backward and lateral velocity |
| Right stick left/right | Turning |
| `B` | Stop the control loop |
| Hold both triggers for 2 seconds | Safe shutdown |

When the gamepad is connected, the service disables Wi-Fi to improve 2.4GHz Bluetooth stability. Turn off the controller when you need SSH; Wi-Fi will be restored automatically.

## Common Commands

Run these from the `microduck/` directory on your development computer:

| Command | Description |
| :--- | :--- |
| `make sync` | Sync local deployment code to `~/microduck` on the Pi. |
| `make setup` | Sync code and run `uv sync --frozen` on the Pi. Use after dependency changes. |
| `make run` | Sync and start the control loop. |
| `make stop` | Stop the control loop. |
| `make shutdown` | Safely shut down the Pi. |
| `make imu` | Print IMU/gyro data. |
| `make voltage` | Read servo voltage. |
| `make voltage ID=2` | Read voltage from a specific servo. |
| `make gamepad-headless-enable` | Install and enable the headless gamepad service. |
| `make gamepad-headless-disable` | Disable the headless gamepad service. |

## Updating the Model

The ONNX model exported from `mjlab_microduck/` should be placed at:

```bash
microduck/src/agents/walk.onnx
```

Then sync:

```bash
cd microduck
make sync
```

The next run will load the new `walk.onnx`.

## Rebuilding a Release Image

After the Pi system, dependencies, services, and model have been tested, the SD card can be turned into a new `microduck.img.xz`.

Recommended workflow:

1. Test `make run` or headless gamepad mode on the real robot.
2. Shut down the Pi and insert the SD card into your computer.
3. Clone the full card to a local `.img` file.
4. Clean sensitive information only inside the cloned image:
   - Wi-Fi credentials.
   - SSH host keys.
   - User SSH keys.
   - `/etc/machine-id`.
   - cloud-init state.
   - shell history, logs, and apt cache.
5. Reset `bootfs/network-config` to placeholder values.
6. Verify that `~/microduck/src/agents/walk.onnx`, `.venv`, and `microduck-gamepad.service` exist.
7. Use PiShrink to create `microduck.img.xz`.
8. Compute SHA256 and record the checksum in the README or Release notes.

Detailed steps are in:

```bash
microduck/docs/dev/clone_sd.md
```

## Directory Layout

```text
.
├── README.md
├── microduck/
│   ├── Makefile
│   ├── src/
│   │   ├── main.py
│   │   ├── scheduler.py
│   │   ├── robot_controller.py
│   │   ├── imu_reader.py
│   │   ├── agents/walk.onnx
│   │   └── moves/walk.py
│   ├── systemd/
│   └── docs/
└── mjlab_microduck/
    ├── src/mjlab_microduck/
    └── logs/
```

## Troubleshooting

### `microduck.local` Cannot Be Found

Wait 1 to 3 minutes first. If it still cannot be found:

- Make sure the Wi-Fi is 2.4GHz.
- Make sure the YAML indentation in `network-config` is unchanged (method 1).
- If you used method 2, run `nmcli device wifi list` and `hostname -I` on the Pi to confirm it joined 2.4GHz Wi-Fi and has an IP.
- Check the Pi's IP address in your router.
- Login with `ssh user@<IP>`.

### SSH Says Host Key Changed

The release image regenerates SSH host keys on first boot. If your computer previously connected to another card, clear the local entry:

```bash
ssh-keygen -R microduck.local
ssh-keygen -R <IP>
```

### Servos Do Not Move or Communication Fails

Check:

- Battery voltage.
- OpenRB-150, servo bus, Raspberry Pi power, and common ground.
- Servo IDs match the table above.
- Dynamixel baud rate is 1Mbps.
- OpenRB-150 USB serial port is detected.
- Cable order, splitters, and connector direction.

### SSH Disconnects When the Gamepad Connects

This is expected in headless mode. The service disables Wi-Fi when the gamepad is connected to improve Bluetooth stability. Turn off the controller and Wi-Fi will be restored.

### The Robot Falls Immediately

Hold the robot first, then check:

- Left/right leg servo IDs are not swapped.
- Knee offsets match the physical assembly.
- IMU mounting orientation is correct.
- `walk.onnx` matches the current hardware.

## Safety Notes

- Hold the robot during the first run.
- Do not test near the edge of a table.
- Do not run for a long time on low battery.
- Do not cut power directly. Use `make shutdown` or the gamepad shutdown gesture first.
- Before charging or powering on, check for shorts, polarity, and insulation.

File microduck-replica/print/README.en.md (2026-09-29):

# Download print files from the CAD repository

[简体中文](README.md) · **English**

**Models, mechanical parts and printing projects are maintained in [fanhao375/microduck-replica-cad](https://github.com/fanhao375/microduck-replica-cad). Select the version matching your servos there.**

| Servo | Download |
|---|---|
| Feetech HD-1910 | [CAD repository](https://github.com/fanhao375/microduck-replica-cad); current checked release: [v2.1](https://github.com/fanhao375/microduck-replica-cad/releases/tag/v2.1), as of 2026-09-28 |
| Dynamixel XL330 | [CAD repository](https://github.com/fanhao375/microduck-replica-cad); current checked release: [v1.1](https://github.com/fanhao375/microduck-replica-cad/releases/tag/v1.1), as of 2026-09-28 |
| Materials, quantities and assembly | [CAD documentation and BOM](https://github.com/fanhao375/microduck-replica-cad#装配-bom) |

**Do not mix mating parts from the Feetech and XL330 versions.** The old STLs here came from the upstream XL330 simulation model and did not include the Feetech CAD changes. They were removed on 2026-09-28 to prevent incorrect prints; Git history retains them for reference. This repository no longer maintains a second download copy of those models.

At the time of this check, the CAD repository's **09-15 3MF does not include the v2.1 combined TPU wheel**. Check each file's version before printing; that change affects the roller variant. SolidWorks and STEP downloads are CAD sources, not sliced printer files.

Meshes retained in `software/training/` and the web servo console are for simulation/display, **not manufacturing**. Their geometry, mass and inertia have not been updated to match the latest physical CAD in this change.

CAD modelling and documentation are by **机械行者Robo**, under **CC BY-NC-SA 4.0** as derivatives of the upstream models. See the CAD repository for attribution, licensing and later versions.

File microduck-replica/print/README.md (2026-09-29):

# 打印文件统一到 CAD 仓库下载

**简体中文** · [English](README.en.md)

**模型、结构件和打印工程统一维护在 [fanhao375/microduck-replica-cad](https://github.com/fanhao375/microduck-replica-cad)。请从那里选择与你的舵机对应的版本。**

| 使用的舵机 | 下载入口 |
|---|---|
| 飞特 HD-1910 | [CAD 仓库 · 飞特版](https://github.com/fanhao375/microduck-replica-cad#两个版本选一个下)；截至 2026-09-28 为 [v2.1](https://github.com/fanhao375/microduck-replica-cad/releases/tag/v2.1) |
| Dynamixel XL330 | [CAD 仓库 · XL330 版](https://github.com/fanhao375/microduck-replica-cad#两个版本选一个下)；截至 2026-09-28 为 [v1.1](https://github.com/fanhao375/microduck-replica-cad/releases/tag/v1.1) |
| 材料、数量、装配步骤 | [CAD 仓库说明与装配 BOM](https://github.com/fanhao375/microduck-replica-cad#装配-bom) |

**不要混用飞特和 XL330 的配合件。** 两种舵盘结构不同；本仓之前的 STL 来自上游 XL330 仿真模型，没有同步飞特改件。

2026-09-28 已从本目录移除旧 STL，避免下载后直接误打。旧文件仍可在 Git 历史中追溯，但不再作为当前打印包提供；主仓不再维护第二份模型下载副本。

截至本次核对，CAD 仓库的 **09-15 旧 3MF 尚未包含 v2.1 的 TPU 合体轮胎**。打印前以 CAD 仓库对应文件的版本说明为准，不要将旧 3MF 当成完整 v2.1；此差异只涉及轮滑变体。SolidWorks / STEP 包是 CAD 源文件，不是已经切片的打印文件。

主仓 `software/training/` 和网页调试台中保留的网格用于仿真及显示，**不是打印来源**。本次调整没有把这些模型、质量或惯量同步为最新实物 CAD。

图纸由 **机械行者Robo** 建模整理，依据上游模型采用 **CC BY-NC-SA 4.0**；作者、许可及后续版本以 [CAD 仓库](https://github.com/fanhao375/microduck-replica-cad) 为准。

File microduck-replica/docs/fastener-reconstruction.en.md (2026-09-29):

# Fastener Reconstruction

> ⚠️ **This English version lags behind the Chinese original.** Several corrections (camera rotation, MK1 part number, U10 placement, STS3032 torque basis, board SKU) were applied to the Chinese docs first. **When the two disagree, the Chinese version wins.** Last sync: 2026-09-05.

[简体中文](紧固件反推.md) · **English**

There is no mechanical BOM upstream and no screw list (the HAT board has an electronics BOM, but it covers no structural parts). Everything below was **recovered from the
geometry of the 47 STL meshes.**

## Method

`scripts/analyze_holes.py`:

1. Weld duplicate vertices, build a face-adjacency graph
2. Cut at a 35° dihedral angle and region-grow "smooth surface patches" (breaks at sharp
   edges)
3. Fit a cylinder to each patch — a cylinder's face normals are all perpendicular to its
   axis, so **the axis is the smallest eigenvector of the normal covariance matrix**
4. Project the vertices onto the plane perpendicular to that axis and fit a circle
   (Kåsa algebraic fit) for the diameter; discard anything with >3 % relative residual
5. Normals pointing toward the axis = **a hole**; pointing away = a shaft or boss, excluded
6. Measure angular coverage and keep only complete circles (≥300°)

All 47 parts scan in 2.5 seconds.

## Conclusion: The Whole Robot Is an M2 System

Diameter distribution of complete circular holes across the structural parts:

| Diameter | Count | Reading |
|---|---|---|
| **Ø2.2** | **77** | **M2 clearance hole** (standard M2 clearance is 2.2–2.4) |
| **Ø4.4** | **28** | **M2 counterbore** (M2 socket-head cap dia. is Ø3.8; counterbore 4.0–4.5) |
| **Ø1.6** | **20** | **M2 tapping hole** (the standard M2 tap drill is exactly 1.6) |
| Ø2.4 | 22 | loose M2 clearance |
| Ø2.0 | 12 | tight M2 clearance |
| Ø2.7 / Ø2.8 | 20 | M2.5 clearance (a small number) |
| Ø4.8 | 10 | M2 counterbore, a second depth |
| Ø5.4 / Ø6.0 | 16 | shaft bores / bearing seats — not fasteners |

**Ø2.2 and Ø4.4 appear as a pair** on `yaw2roll`, `leg`, `ankle_left`, `neck_pitch` and
`yaw_roll_motion` — the classic **clearance hole + counterbore** combination, which
confirms **M2 socket-head cap screws**.

Cross-check: `xl330.stl` itself carries **4× Ø2.0 + 8× Ø1.6**, matching the Dynamixel
XL330's own M2 mounting pattern.

## Per-Part Hole Counts

Weighted by how many times each mesh is actually used in the full robot:

| Mesh | Uses | M2 clearance | M2 tap | Counterbore |
|---|---|---|---|---|
| `xl330` | **×15** | 4 | 8 | — |
| `hip_l` | ×2 | 9 | — | 6 |
| `yaw2roll` | ×2 | 8 | — | 6 |
| `leg` | ×2 | 6 | — | 6 |
| `neck_pitch` | ×1 | 12 | — | 4 |
| `face_part` | ×1 | 10 | 4 | — |
| `ankle_left` / `ankle_right` | ×1 each | 5 | — | 5 |
| `yaw_roll_motion` | ×1 | 4 | — | 6 |
| `power_support` | ×1 | — | 8 | — |
| `left_shell` / `right_shell` | ×1 each | 7 / 6 | — / 1 | — |
| `bearing_roll` | ×2 | 4 | — | — |
| `neck` | ×2 | 4 | — | — |
| `upper_leg_rigidity_plate` | ×2 | 4 | — | — |
| `jaw` | ×1 | 5 | — | — |
| `trunk_base` | ×1 | 4 | — | — |
| `bottom_head_shell` / `top_head_shell` | ×1 each | 4 / 3 | — | — |
| `m12_lens_holder` | ×1 | 3 | — | — |

> **`xl330` appears 15 times** — the robot has 15 servos, not 14. Fourteen are under policy
> control; the fifteenth drives the beak/jaw through a `passive_*` linkage and never enters
> the action space. This matches the "15 servos" in the official README.

## Purchase Estimate

- M2-class holes (Ø1.9–2.5 mm, ≥300° wrap) across the assembly, **weighted by usage: 237**,
  of which 60 are on the servo bodies (15×4), 21 on bought parts (bearings / PCBs / battery),
  and about 156 on printed structural parts

  > ⚠️ **Correction (2026-09-04)**: earlier versions said "213", which does not reconcile. Two
  > causes: the earlier count was **not weighted by how often each part is used** (`leg` is ×4,
  > `hip_l` and `yaw2roll` are ×2), and it **included meshes no MJCF references**. The diameter
  > and depth tables below are **unweighted** (each STL counted once) — the two cannot be summed.
  themselves (15 × 4)
- Excluding servos and bought-in parts (bearings, PCBs, battery), the structural parts
  account for **roughly 146 clearance holes**

**Suggested quantities** (including losses and trial fitting):

| Spec | Suggested | For |
|---|---|---|
| M2×4 socket head | 60 | thin-wall positions (51 of 79 holes are 0–3 mm deep) |
| M2×6 socket head | 80 | the workhorse size |
| M2×8 socket head | 40 | 3–5 mm deep positions (24 of 79) |
| M2×12 socket head | 15 | a few deep holes (8–12 mm, 4 places) |
| M2 nuts | 50 | where there is nothing to tap into |
| M2 heat-set inserts | 60 | recommended over tapping printed plastic directly |
| M2.5×6 | 20 | the handful of Ø2.7 positions |

Lengths are inferred from the measured depth distribution of the Ø2.2 holes: 51 at
0–3 mm, 24 at 3–5 mm, 4 at 8–12 mm.

## Bearings

| Source file | Measured |
|---|---|
| `seeed_bearing__configuration__22x16x4` | **OD 22 × ID 16 × W 4 mm** |
| `seeed_bearing__configuration_default` | OD 15 × ID ~10 × W 3 mm (×3 in the robot) |

## ⚠️ Limitations

1. **This is recovered from simulation meshes, not from engineering drawings.** Simulation
   meshes only guarantee correct outer shape and inertia — not fit tolerances or complete
   thread detail.
2. **Print shrinkage changes the real hole size.** A Ø2.2 design hole typically comes out
   0.1–0.3 mm undersize on FDM. Print a test piece and check before committing to a build.
3. **Counterbores and clearance holes may be double-counted** (two features of the same
   screw). Screw counts here are based on clearance holes only; counterbores are not
   counted separately.
4. **Features not detected:** non-circular holes (slots, shaped cutouts), partial arcs with
   <300° coverage, and openings larger than Ø14 mm are all outside the statistics.
5. Screw **lengths** are ranges inferred from hole depth, not measured values.

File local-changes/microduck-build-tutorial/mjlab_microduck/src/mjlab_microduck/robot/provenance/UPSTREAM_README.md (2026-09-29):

# Microduck RL



RL training environments for [Microduck](https://github.com/pollen-robotics/microduck) —
a ~800 g, ~25 cm tall bipedal robot — built on
[mjlab](https://github.com/mujocolab/mjlab) (MuJoCo Warp) with PPO.
Policies are trained here at 50 Hz, exported to ONNX, and deployed on the real
robot by the runtime in [pollen-robotics/microduck](https://github.com/pollen-robotics/microduck).

<!-- HERO VIDEO — real robot montage: walking, standup, roulade, roller skating.
     Keep it short (~30 s) and real-robot-first: this is the "why should I care" shot. -->

https://github.com/user-attachments/assets/50c3d537-8db2-4005-9d9c-3472faeec4d0

The repo encodes the full sim2real recipe: [BAM](https://github.com/Rhoban/bam)
actuator physics, domain randomization, backlash simulation, and the
reward-design lessons that made it work
(see [AGENTS.md](AGENTS.md) for the distilled playbook).

## Quickstart

Requires a CUDA GPU (training runs through MuJoCo Warp) and [uv](https://docs.astral.sh/uv/).

> **On ARM boxes (DGX Spark / GB10, Jetson):** `uv sync` pulls ~2 GB of CUDA
> wheels on first run and uv's default 30 s HTTP timeout can abort mid-download.
> Export `UV_HTTP_TIMEOUT=600` for the first sync. 

```bash
git clone https://github.com/pollen-robotics/microduck_rl
cd microduck_rl

# train the walking policy (uses your GPU; ~1-2 h for a usable gait at 4096 envs)
uv run train Mjlab-Velocity-Flat-MicroDuck --env.scene.num-envs 4096

# watch a trained policy in the viewer
uv run play Mjlab-Velocity-Flat-MicroDuck --wandb-run-path <entity/project/run_id>

# export to ONNX for deployment
uv run scripts/export.py Mjlab-Velocity-Flat-MicroDuck --wandb-run-path <...>
uv run publish --onnx output.onnx --repo <user>/microduck-<name> --kind episodic --duration-s 4.0   # share it (see "Publishing a policy")

# drive the exported policy in CPU MuJoCo with the keyboard
uv run scripts/infer_policy.py --walking output.onnx
```

Resume from a checkpoint:

```bash
uv run train Mjlab-Velocity-Flat-MicroDuck --env.scene.num-envs 4096 \
    --agent.run-name resume --agent.load-checkpoint model_29999.pt --agent.resume True
```

No GPU? Add `--hf-jobs` to any train command to run it on Hugging Face Jobs
instead of locally (see [scripts/hf/README.md](scripts/hf/README.md)).

## Tasks

`uv run list-envs` prints the live registry. Flat/Rough variants exist where noted.

<!-- SHOWCASE GRID — one short GIF per task family (sim or real), 3 per row.
     Priority order if you only record a few: Velocity, VelStand (fall+recover),
     Roulade, SitStand, Rollers/Swizzle, BallKick. -->

| Task id | Terrain | Description |
|---|---|---|
| `Mjlab-Velocity-{Flat,Rough}-MicroDuck` | flat/rough | **The main task**: walking with velocity commands + head-pose commands |
| `Mjlab-VelStand-{Flat,Rough}-MicroDuck` | flat/rough | Walking + fall recovery in one policy |
| `Mjlab-StandUp-{Flat,Rough}-MicroDuck` | flat/rough | Stand up from face-down/face-up/sitting, then hold the stand + body-pose control |
| `Mjlab-SitStand-{Flat,Rough}-MicroDuck` | flat/rough | Commanded sit ↔ stand in one policy, gently, head commandable |
| `Mjlab-GroundPick-{Flat,Rough}-MicroDuck` | flat/rough | Crouch and touch the ground with the mouth tip, return to stand |
| `Mjlab-BallKick-Flat-MicroDuck` | flat | Kick a 70 mm / 15 g ball forward (actor is ball-blind) |
| `Mjlab-Roulade-Flat-MicroDuck` | flat | Forward roll over the head, land back on the feet |
| `Mjlab-Velocity-Flat-MicroDuck-Rollers` | flat | Roller-skate velocity tracking (passive wheels under the feet) |
| `Mjlab-Velocity-Swizzle-MicroDuck` | flat | Classic symmetric swizzle skating |
| `Mjlab-RollerCrouch-Flat-MicroDuck` | flat | Crouch while gliding on rollers |
| `Mjlab-RollerSlope-Flat-MicroDuck` | slope | Glide down slopes on rollers |
| `Mjlab-RollerStandUp-Flat-MicroDuck` | flat | Stand up from the ground onto the wheels |
| `Mjlab-Spin-Flat-MicroDuck` | flat | Fast spin in place on rollers |

At deployment the runtime hot-swaps these policies (walk / recover / trick)
behind a shared 61-dimensional observation contract, so any of them can take
over the robot at any moment. `scripts/infer_policy.py` rehearses exactly that:

```bash
uv run scripts/infer_policy.py --walking walk.onnx --standing stand.onnx \
    --sitstand sitstand.onnx --roulade roulade.onnx --new-cmd-obs
```

Keyboard-driven (velocity commands, `G` ground pick, `Y` sit/stand, `R` roulade,
`K`/`L` kicks); `--debug`, `--save-csv`, `--record` support sim2real comparisons.
The servos are simulated with the same BAM M6 XL330 model the policies are
trained against (voltage control + load-dependent friction, via
`bam.mujoco.MujocoController`); `--vin` / `--vin-drop-gain` / `--kp-fw` pin the
training DR ranges to one value, `--no-bam` falls back to the XML PD actuators.

### Backlash variants

Every main task has a **Backlash** twin that trains on a model with ±1° of gear
play (2° total) in series with each of the 14 servo joints: insert `-Backlash`
before `MicroDuck` in the task id, e.g. `Mjlab-Velocity-Flat-Backlash-MicroDuck`.

The backlash is modeled properly for sim2real: each servo gets an unactuated
`passive_<joint>_backlash` hinge, and because the real encoder sits on the
output side of the play, both the firmware PD emulation
(`BacklashEncoderBamActuator`) and the `joint_pos`/`joint_vel` observations
read *through* the backlash (`qpos[servo] + qpos[backlash]`). Observation and
action dims are unchanged, so ONNX export and the runtime need no changes.
See `src/mjlab_microduck/tasks/backlash.py`.

## Actuator model

All tasks use the [BAM](https://github.com/Rhoban/bam) M6 actuator model for
the Dynamixel XL330 (voltage control law, back-EMF, Coulomb/Stribeck/load-dependent
friction), with per-env domain randomization on battery voltage, voltage sag
under load, command delay, and friction magnitude
(`FrictionDRBamActuator` in `src/mjlab_microduck/actuator/`).

At this scale — tiny servos driving a ~800 g biped — actuator fidelity is most
of the sim2real gap, which is why the actuator is modeled down to its voltage
control law instead of an ideal PD.

## Robot models

MJCF models live in `src/mjlab_microduck/robot/microduck/` and are exported
from Onshape with [onshape-to-robot](https://github.com/Rhoban/onshape-to-robot),
one `config_mjcf_*.json` per model:

| XML | Used by |
|---|---|
| `robot_walk.xml` | Velocity (stripped trunk/head contacts — falling is cheap) |
| `robot_groundcontact.xml` | VelStand, StandUp, SitStand, GroundPick, BallKick, Roulade (curated collision set for the parts that touch the floor — body can physically lie on the ground; formerly `robot_allcollisions.xml`) |
| `robot_groundcontact_rollers.xml` | Roller tasks (passive wheels) |
| `robot_allcollisions.xml` | True full-collision model — every part has a collision geom. No task uses it yet |
| `robot_*_backlash.xml` | Backlash task variants (generated by `add_backlash.py`) |

`scene*.xml` files wrap the robots with a floor + keyframes (STAND/SIT/FOLD)
for quick viewing and for `infer_policy.py`.

<!-- IMAGE — side-by-side render: walk model vs rollers model (or a collision-geom
     visualization). One image here makes the model-variant story instant. -->

## Project structure

```
src/mjlab_microduck/
├── robot/
│   ├── microduck/                    # MJCF exports, export configs, scenes, add_backlash.py
│   └── microduck_constants.py        # robot cfgs, HOME frame, BAM actuator cfg
├── actuator/friction_dr_bam.py       # BAM + friction DR + backlash encoder feedback
├── tasks/
│   ├── __init__.py                   # task registration (base + backlash variants)
│   ├── mdp.py                        # rewards, events, observations, custom classes
│   ├── backlash.py                   # make_backlash_variant() env-cfg wrapper
│   └── microduck_*_env_cfg.py        # one cfg module per task family
├── train_cli.py                      # `train` script (identical to mjlab's)
├── train_hook.py                     # intercepts `train ... --hf-jobs`
└── hf_jobs.py                        # Hugging Face Jobs submission
```

Conventions worth knowing:

- The observation layout is shared across every policy (61-dim actor obs:
  48 proprioception + commands `[twist(3), head_pose(4), body_pose(6)]`), which
  is what makes runtime policy hot-swapping possible. Envs that don't use a
  command slot zero-pad it rather than dropping it.
- Unactuated joints are all named `passive_*` (roller wheels, backlash
  hinges); actuators, joint observations and pose rewards select servo joints
  with `^(?!passive_).*`.
- Domain-randomization toggles are `ENABLE_*` booleans at the top of each
  env cfg file.
- Joint layout (14 servos): 0–4 left leg (hip_yaw, hip_roll, hip_pitch, knee,
  ankle), 5–8 neck/head (neck_pitch, head_pitch, head_yaw, head_roll),
  9–13 right leg.
- The exporter bakes the observation normalizer into the ONNX graph — always
  deploy ONNX produced by `scripts/export.py`, never a hand-converted
  checkpoint, or the policy sees unnormalized observations at runtime.

[AGENTS.md](AGENTS.md) documents the env-building workflow and the reward-design
rules learned across the project (also aimed at AI coding agents working in
this repo).

## Publishing a policy

`uv run publish` puts a policy on the Hugging Face Hub in the shape the robot's
daemon loads: one `policy.onnx` with the observation normalizer baked in, a
`manifest.json` following schema 2 of the
[microduck policy manifest](https://github.com/pollen-robotics/microduck/blob/main/docs/policy-manifest.md),
and a README saying how to run it. Anyone with a microduck can then install it
with one command, no daemon release needed.

```bash
# From a wandb run — exports through the one safe path, then uploads
uv run publish --task Mjlab-PoliteBow-Flat-MicroDuck \
    --wandb-run-path <entity/project/run_id> --checkpoint 3000 \
    --repo <user>/microduck-polite-bow --kind episodic --duration-s 4.0 \
    --description "Bows from a two-foot stand and comes back up."

# From an ONNX you already exported (validated, not re-exported)
uv run publish --onnx output.onnx --repo <user>/microduck-flamingo \
    --kind perpetual --unwind-s 1.5 --twist-help "[flag, side, 0]"

# A new gait for a slot
uv run publish --onnx output.onnx --repo <user>/microduck-my-walk --kind perpetual --slot walk

# See what would be uploaded without touching the Hub
uv run publish --onnx output.onnx --repo <user>/microduck-bow --kind episodic --duration-s 4.0 --dry-run
```

Then on a robot:

```bash
sudo robotctl policy add polite-bow <user>/microduck-polite-bow   # episodic: length comes from the manifest
sudo robotctl policy add flamingo <user>/microduck-flamingo --hold 5   # held pose: you pick how long
sudo robotctl policy load walk <user>/microduck-my-walk                # gait: into the walk slot
robotctl robot do polite-bow
```

What `--kind` means, and what each needs:

- **episodic** — runs for `--duration-s` and returns itself to a standing pose
  (kicks, roulade, a bow). Add `--chain` if holding the button should repeat it.
- **perpetual** — runs until told otherwise. Two shapes:
  - a **gait** (a new walk or stand): add `--slot walk` (or `stand`) and
    nothing else; the owner installs it with `robotctl policy load walk <repo>`.
  - a **held pose** (the flamingo): give `--unwind-s`, how long the daemon
    drives the idle twist (`--idle`, zeros by default) before handing back to
    the gait, so the robot is not let go of on one foot. The owner runs it as a
    one-shot with `policy add ... --hold <seconds>`.

Before anything is uploaded, `publish` checks the graph is `[1,61] -> [1,14]`
(a 51-D legacy policy is refused with a message), runs it on plausible inputs
and refuses NaNs or a constant output, fills the `training` block from git and
wandb (task, commit, branch, dirty flag, run, checkpoint), and refuses to
overwrite an existing `.onnx` in the repo without `--force`. Repos are created
private; `--no-private` for public, `--tag v1` to tag the revision.

Only constant-command policies are publishable this way. Phase-driven moves
(the ground pick) and the posture-flag sit↔stand are driven by the daemon
itself and live in the official set, `pollen-robotics/microduck-policies`.

## Tests

```bash
uv run --with pytest pytest tests/
```

CPU-only config-invariant and reward-function regression tests — they lock in
joint-index mappings, reward sign conventions, and NaN guards.

## Related projects

- [microduck](https://github.com/pollen-robotics/microduck) — the Microduck project home, including the onboard runtime that runs the exported policies
- [mjlab](https://github.com/mujocolab/mjlab) — the training framework (MuJoCo Warp + rsl_rl)
- [BAM](https://github.com/Rhoban/bam) — better actuator models, by Rhoban

## License

This project is licensed under the Apache 2.0 License. See the [LICENSE](LICENSE) file for details.
3D model files are licensed under Creative Commons BY-SA-NC.

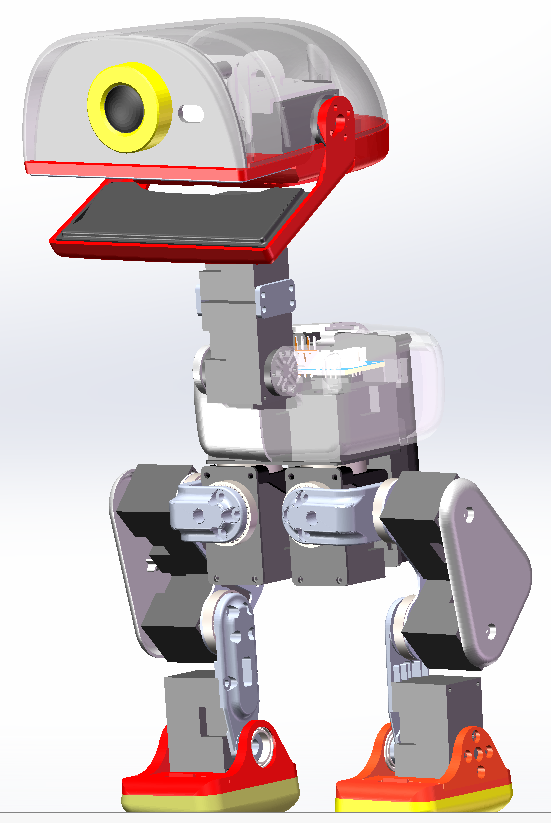
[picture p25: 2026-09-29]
microduck-replica/assets/cad-solidworks-装配体.png

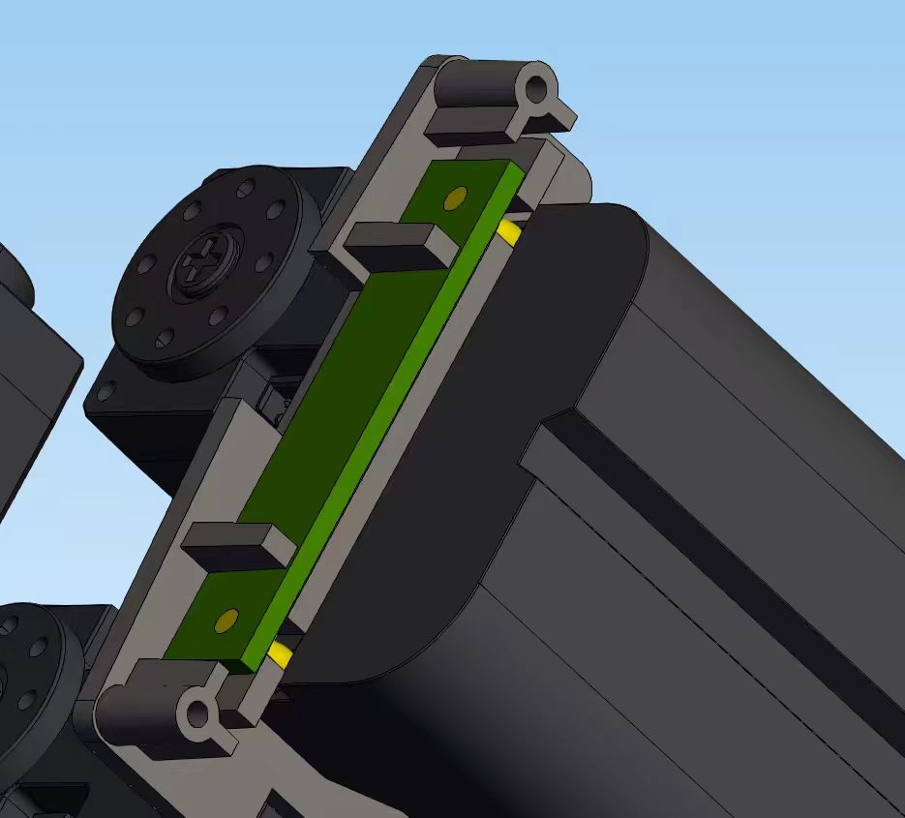
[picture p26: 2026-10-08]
hardware/banana_pcb/docs/img/banana_assembly_render.jpg

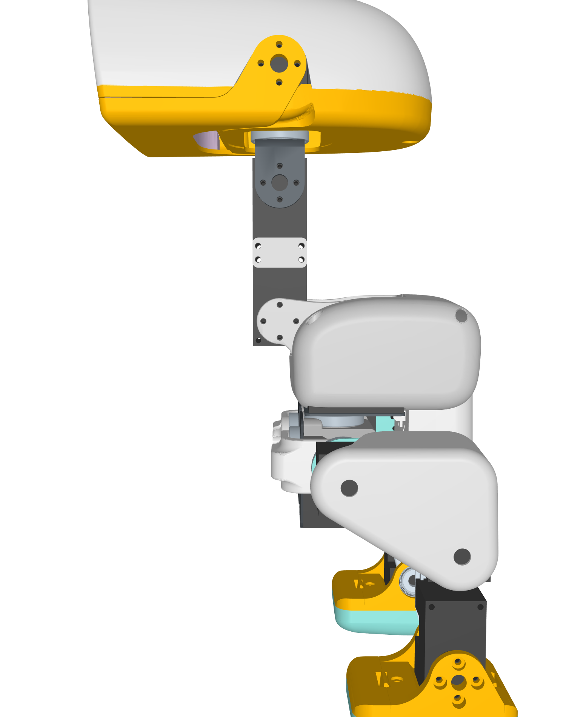
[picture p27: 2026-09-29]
microduck-replica/assembly-drawings/03_背面.png

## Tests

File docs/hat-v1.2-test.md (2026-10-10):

# HAT V1.2 功能确认操作单（Microduck Controller Hat for Radxa Zero 3W）

> **目的**：实物丝印 V1.2，存档原理图仅 V1.0（图物差异：背面 F303 类 MCU + 正面超级电容，见 [docs/photos/](./photos/README.md) HAT 小节）。没有 V1.2 图纸，本操作单**不做图物比对**，只用「断电通断核对 + 限流上电分步验证」确认本项目需要的功能是否 OK。
>
> **需要确认的 4 项必需功能**（依据 [power-architecture-v2.md](./power-architecture-v2.md)）：
>
> | # | 功能 | 判定门 |
> |---|---|---|
> | 1 | +BATT 进 → 板内降压 → 5V 经 40P 排母喂 Radxa | B2：排母 pin2/4 = 5.0V ±0.2 |
> | 2 | 舵机口 pin2 = 电池直通（能过 3-5A） | A2：pin2 ↔ +BATT 网导通，中间无串联件 |
> | 3 | Radxa UART2（ttyS2）→ 半双工驱动 → 舵机口 pin3 | B5：一颗舵机 ping 通 |
> | 4 | 舵机口针序 1=GND / 2=+BATT / 3=DATA | A1 |
>
> 附加排除项：F303 MCU 不干扰总线与电源（A4 + B6）。音频/RS485/板载 IMU/Qwiic 飞特路线不用，不测。
>
> 装备：德力西 6000 位万用表、德力西 DLX-30V10AMF 直流电源、Radxa Zero 3W（已烧卡可 ssh）、已配好 ID 的 HD-1910 ×1、杜邦线若干。
> 全程原则：**先断电核对，后限流上电**；首次上电限流 0.3A。板正反面照片与元件标注：`docs/photos/hat-v1.2-*.jpg`。

## A 断电核对（万用表蜂鸣/电阻档，板子不上电、不插 Radxa）

- [ ] A1 **舵机口针序**（两个 SERVOS 大白座都量）：
      pin1 ↔ 排母 pin6 或安装孔（GND）应**通**；pin1↔pin2、pin2↔pin3 应**不通**；两座 pin2↔pin2 应**通**（并联）。
      认准 1 脚方向再量，结果与丝印对照拍照存档
- [ ] A2 **+BATT 路径**：舵机口 pin2 ↔ AP63205 输入电容正极（正面 CK 6R8 电感旁）应**直通**；
      若不通或电阻档有阻值 → 中间串了保险/开关件，记下阻值并拍照识别。
      **同时定位电池入口**：用 pin2 逐个碰背面 8 个圆形焊盘，找出 +BATT 实际进板位置（决定电池线焊/插在哪），记入结果
- [ ] A3 **排母关键脚**：pin2/4（5V）↔ 排母附近 5V 网络应通；pin8/pin10（UART2 TX/RX）↔ 正面 74LVC 小芯片区应通（电阻档几十~几百 Ω 也算有路径，直通件是 0Ω 选路电阻）
- [ ] A4 **MCU 粗查**（F303 是旁观者还是参与者）：蜂鸣档从舵机口 pin3 出发扫 F303 四边引脚；再从排母 pin8/10 出发扫一遍。
      都不通 → MCU 不在舵机数据链上（旁观者）；有任一通 → 记下脚位，B6 重点观察
- [ ] A5 **超级电容**：断电态两端电压 ≈0；一端应接 3.3V 轨或 MCU 的 VBAT 脚（蜂鸣粗查），确认它不是动力链的一部分

## B 限流上电（台架电源，限流 0.3A 起步）

- [ ] B1 电源设 **8.4V / 限流 0.3A**，接 A2 找到的 +BATT 入口（红正黑负，接前拍照核对极性）
- [ ] B2 **5V 判定门**：开输出，HAT 空板（不插 Radxa、不接舵机）。正常：红屏几十 mA；量排母 pin2/4 = **5.0V ±0.2** → 过。
      电流顶限 = 短路，立即关输出查；无 5V = 电源链与 V1.0 不同（可能 F303 参与电源时序），停、拍照、记录
- [ ] B3 **总线空闲电平**：舵机口 pin3 对 GND ≈ 3.3V（上拉）；pin2 = 8.4V。pin3 若是 5V → 停，数据电平与 Radxa/IMU 的 3.3V 体系不符，需另查
- [ ] B4 **插 Radxa 点亮**：关输出 → 插 40P 排母 → 开输出。Radxa 灯语双闪→常亮，ssh 进系统，`ls -l /dev/ttyS2` 应在且无人占（`sudo fuser -v /dev/ttyS2`）
- [ ] B5 **一颗舵机 ping 通**（数据链判定门）：舵机插舵机口，Radxa 上 `feetech-servo-sdk` 以 1 Mbps ping 该 ID → 应答 = 功能 3 通过
- [ ] B6 **MCU 干扰排除**：不跑任何软件静置 5 分钟——舵机不自转、无异响、不失力矩；（可选）跑 bench 工具总线错误计数 = 0。
      若舵机有异常动作或总线有非预期数据 → F303 在往总线发数据，停，向板卡来源要固件说明
- [ ] B7（可选）PWR_DET 关机检测：排母对应 GPIO 脚电平随 +BATT 有无变化则该功能在

## 异常速查

| 现象 | 含义 | 动作 |
|---|---|---|
| B2 电流顶 0.3A、电压被压低 | 短路或接反 | 关输出，蜂鸣档查 +BATT 对 GND |
| B2 无 5V、电流正常小 | V1.2 电源链改了（疑 MCU 控 EN） | 量 AP63205 EN 脚电平；拍照记录，找来源 |
| B3 pin3 = 5V | 数据电平不符 | 停；查 V1.2 是否换了驱动供电轨 |
| B5 ping 不通 | 链路任一环断 | 顺序查：ttyS2 在否 → 占用否 → A3 结果 → 舵机 ID/波特率；最后用微雪板验证舵机本身好坏 |
| B6 舵机自转/数据乱 | F303 在抢总线 | 停；要固件说明或断开 MCU 总线脚（最后手段） |

## 收尾

- [ ] E1 全部结果（通断表、电压、电流、ping 截图）记入 PROGRESS.md，勾掉「HAT V1.2 适配核对」待办
- [ ] E2 结论二选一：**全过** → HAT 可用于整机，v2 架构不变；**MCU 干扰或 5V 链不符** → 转微雪板「不打 HAT」路线（replica 文档有现成手顺），HAT 等 V1.2 图纸

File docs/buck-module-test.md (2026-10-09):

# 降压模块实测操作单（BUS SERVO POWER SUPPLY V1.3）

> **2026-10-10 实测完成（空载）**：
>
> | 输入 V | VCC(3P) | PWR OUT(2P) | 判读 |
> |---|---|---|---|
> | 12.0 | 6.00V | 12V | 稳压正常 / 直通 |
> | 7.0 | 6.00V | — | 稳压保持 |
> | 6.6 | 6.00V | 6V | **2S 带载最差点，稳压保持** ✓ |
> | 6.3 | 5.99V | — | 拐点：开始跌落 |
> | 6.0 | 5.7V | 6V | 跌落跟随（输入−0.3V） |
> | 5.0 | 4.7V | 5V | 跌落跟随 |
>
> **结论**：① 选压桥 = **6V 档** ② 实测稳压输入下限 **≈6.3V**（压差 ~0.3V，跌落跟随非关机，远好于丝印 7.2V）③ PWR OUT = 电池直通口 ④ **2S 电池初判可用**（6.6V 最差工况输出仍 6.00V）；改焊 5V 档后拐点降至 ~5.3V，余量更大 ⑤ **接口分工已闭环：XT60 输入 / PWR OUT 直通 / 3P VCC 稳压——"DC 母座"系照片误判，实物无此件（2026-10-10 用户核对）** ⑥ 待办：改焊 5V+空载复验、台架带载复测

> 2026-10-10 建。测试目标：① 确认选压焊盘当前档位 ② 输入下限扫描判定 2S 电池可用性 ③ 分清三个输出口的分工。
> 装备：德力西 DLX-30V10AMF 直流电源 + 德力西 6000 位万用表。照片与元件标注见 [docs/photos/README.md](./photos/README.md)。
> 全程电源限流 **0.3A**；万用表红笔在 VΩmA 孔，档位 V⎓ 60V；表只测电压不测电流（电流看电源红屏）。

## A 准备（约 2 分钟）

- [ ] A1 万用表：黑笔 COM、红笔 VΩmA，旋钮 V⎓ 60V
- [ ] A2 电源输出关（ON/OFF 灯灭），VOLTAGE 拧到 12.0V
- [ ] A3 设限流 0.3A：红黑夹子互相夹住 → 开输出 → 电源跳 C.C. → 拧 CURRENT 到红屏 0.30A → 关输出、分开夹子
      （空载时红屏读不到限流值，必须靠短路夹子来设；若拧 CURRENT 无反应，试按一下旋钮）

## B 接线（电源保持关闭输出）

- [ ] B1 红夹子夹 XT60 座尾部**+**极焊脚/极耳，黑夹子夹**−**（认板面丝印 +/−；夹子别互碰）
      （有 XT60 公头转接线则插上夹线尾，更好）
- [ ] B2 夹好后拍照核对（极性接反 = 烧板），不确定就发给助手看
- [ ] B3 万用表表笔先不接模块

## C 空载输出测量（判定选压档位）

- [ ] C1 开电源输出。正常：绿屏 12.0V，红屏几十 mA（记下来 = 静耗），C.V. 灯亮
- [ ] C2 表笔测背面 3P 排针焊点：红笔 **VCC**、黑笔 **GND**（别碰到相邻针）→ 记入下表
- [ ] C3 测 2P 接线端子（PWR OUT）两脚 → 记入下表
- [ ] C4 ~~测 DC 母座~~（勘误：板上无此件，系照片误判）
- [ ] C5 判定门：VCC ≈ **5.0V** → 过关继续；读出 6V/7V → **停**，接 IMU 前必须改焊 5V 档（IMU LDO 上限 5.5V）

## D 输入下限扫描（判定 2S 可用性）

万用表保持接 VCC/GND，缓慢拧 VOLTAGE 逐点记录：

| 电源输入(V) | VCC/GND 输出(V) | 现象备注 |
|---|---|---|
| 12.0 |  |  |
| 10.0 |  |  |
| 8.0 |  |  |
| 7.5 |  |  |
| 7.2 |  |  |
| 7.0 |  |  |
| 6.8 |  |  |
| 6.6 |  | ← 2S 带载最低点，关键行 |
| 6.4 |  |  |
| 6.0 |  |  |
| 5.5 |  |  |

- [ ] D1 找到输出从标称值开始下滑（−2%，5V 档即跌破 4.90V）的输入电压 = **实测输入下限**
- [ ] D2 判读：下限 ≤6.5V → 2S 可用；6.6~7.2V → 边缘，后台架带载复测；≥7.2V → 2S 不可用
- [ ] D3 PWR OUT 若始终跟着输入变（非稳压）→ 它是电池直通口，判定线同样适用

## E 收尾

- [ ] E1 关电源输出 → 拆表笔 → 拆夹子
- [ ] E2 模块手摸温度（IC/电感温热正常，烫手记录）
- [ ] E3 结果（档位/下限/三口分工/静耗）记入 PROGRESS.md 并勾掉对应待办

## 异常速查

| 现象 | 含义 | 动作 |
|---|---|---|
| 开输出电流顶到 0.3A、电压被压低 | 接反或短路 | 立即关输出，查极性 |
| 输出 0V，电流正常小 | 可能欠压锁定或板故障 | 输入升到 7.5V 以上再试 |
| 输出 4.8~4.9V | 5V 档正常容差 | 记录即可 |
| 输出随输入线性变化 | 桥没焊/直通模式 | 查焊盘，改焊后重测 |

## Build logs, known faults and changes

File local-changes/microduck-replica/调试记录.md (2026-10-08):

# 调试记录

**简体中文**

> **当前状态：HAT 已到货并与主板对插；当前运行瑞莎官方 B1，Wi-Fi / SSH 正常，调整摄像头排线后已采集到 1920×1080 画面。**
> 最后更新：2026-09-28。当前官方系统用于摄像头对照，尚未恢复项目运行时；原 Armbian 在正确接线下尚未复测。

[构建日志](构建日志.md) 记的是**机械**：打印、试装、公差。
这份记的是**电气与软件**：先是**一步一步的操作手册**（拿到货怎么配、怎么接、怎么测），下面是**按日期的过程**（做了什么、看到什么、下一步是什么）。

结论性的坑单独整理在 [踩坑记录](踩坑记录.md)。板子和芯片是什么、为什么这么选，在 [硬件入门](docs/硬件入门.md)。

---

## 进度

| 日期 | 阶段 | 状态 | 备注 |
|---|---|---|---|
| 2026-09-10 | 舵机 + 调试板到货 | ⚠️ 遇到问题 | 调试板 TTL 口跟舵机 2.0 mm 线不匹配 |
| 2026-09-12 | 主控、ToF、电池、电池仓、SD 卡、排针、摄像头到齐 | ✅ 完成 | 排针已焊到 Radxa 上 |
| 2026-09-12 | 舵机装机械件 | ✅ 完成 | **HD-1910 跟 XL330 有结构差异**，改件重打后可适配 |
| 2026-09-13 | 15 颗配 ID | ✅ 完成 | 用剪开的舵机线飞到 URT-2，一颗颗配 |
| 2026-09-13 | 台架通总线（URT-2 ↔ Radxa） | 🔨 进行中 | 电源 7.4V 进 URT-2，USB 进 Radxa host 口 |
| 2026-09-16 | 主控裸板上电 | ✅ 完成 | 无异常 |
| 2026-09-16 | 主控刷机（2G 板 / microSD） | ❌→✅ | Armbian 官方镜像在 V1.12 板上起不来（引导程序），换瑞莎引导后 09-17 起来，见下 |
| 2026-09-17 | 官方脚本 setup-board / migrate-network / install | ✅ 完成 | ttyS2、NetworkManager、ONNX Runtime、daemon 0.13.0 |
| 2026-09-17 | 整机 15 颗上总线（URT-2 ↔ 电脑） | ✅ 完成 | 0 超时 0 校验错，15 颗同步读 4.8 ms；卡了一小时的是 URT-2 上电顺序 |
| 2026-09-17 | 网页调试台 `tools/servo-web/` | ✅ 完成 | 滑块、姿态、序列、3D 跟随、重心显示、寄存器导出 |
| 2026-09-18 | 校零、站姿、缩起来 ↔ 站起来序列 | 🔨 进行中 | 能自己站起来坐下（[视频](assets/首次上电-2026-09-18.mp4)）；零位还有 4 颗要重校，方向反的 4 颗用页面 ± 翻 |
| 2026-09-17 | `imu_to_dxl` 板到货、上电 | ✅ 完成 | 3.3 V 正常。J4/J5 座子间距对但**外壳跟飞特线不匹配**，削掉外壳能插，v2 换座 |
| 2026-09-22 | `imu_to_dxl` 飞特协议固件 0.2.0 | ✅ 桌面验证 / ⚠️ 真总线待测 | 已烧入开发板，IMU 工作；验收边界见[固件说明](hardware/imu_to_dxl/firmware/) |
| 2026-09-28 | HAT 到货、对插与主板上电调试 | 🔨 进行中 | 按主板 → 摄像头逐项检查；不是 HAT 音频、舵机总线及负载验收 |
| 2026-09-28 | 损坏 ID 21 的替换与校中位 | ✅ 用户确认 | 原嘴 ID 34 舵机改作 ID 21，用户用 FD 确认 2048 校准成功；嘴暂缺 |
| 2026-09-28 | 官方 B1 镜像对照 | ✅ 完成 | Wi-Fi / SSH 已实测，启用 Radxa Camera 8M overlay |
| 2026-09-28 | 摄像头识别与出图 | ✅ 短时采集通过 | 调整排线后读到 `0x0219`，40 帧 1920×1080；持续帧率与项目集成待测 |
| 2026-10-09 | 电控件到货 | ✅ 到货 | 微雪 Bus Servo Adapter (A)、黑色降压模块、丝印 IMU2DXL v1.0 的板；白色鸭图案 HAT（V1.1）一并在手（用户确认）。明细见「手头有的」 |
| — | 不打 HAT 飞线接主控 | 📋 备用方案 | 当前先走已到货的 HAT，飞线文档保留 |

图例：📋 计划中 · 🔨 进行中 · ✅ 完成 · ⚠️ 遇到问题 · ❌ 此路不通

---

## 手头有的

| 东西 | 数量 | 状态 |
|---|---|---|
| 飞特 HD-1910-C001 | 原购 15 | 原 ID 21 损坏，嘴 ID 34 挪作 ID 21；当前嘴暂缺，不能沿用“15 颗全在线”作为现状 |
| 飞特 FE-URT-2 调试板 | 1 | ✅ 到货 2026-09-10 |
| Radxa Zero 3W 2 GB（裸板，无 eMMC） | 1 | ✅ 到货 2026-09-12，**排针已焊** |
| Radxa Zero 3W 8 GB + 64 GB eMMC | 1 | 📦 月底 |
| NP-F550 电池 + 电池仓 | — | ✅ 到货 2026-09-12 |
| VL53L8CX ToF | 1 | ✅ 到货 2026-09-12 |
| Radxa Camera 8M219（IMX219） | 1 | ✅ 官方 B1 下识别并出图，2026-09-28 |
| RPI Robot HAT | 1 | ✅ 已到货、已对插；各外设功能逐项调试 |
| 高耐久 microSD | — | ✅ 到货 2026-09-12 |
| 2×20 排针 | — | ✅ 到货并焊上 |
| `imu_to_dxl` PCB + SMT | 5 | ✅ 到货 2026-09-17，¥629.72；上电 3.3 V 正常，连接器封装有问题。2026-10-09 到货照片中另有一块丝印 **IMU2DXL v1.0** 的绿色板（2 个 3P 座 + SWD），与 09-17 批的异同、是否为换座 v2 **待核** |
| 读卡器、5 V 降压模块 | — | ✅ 到货 2026-09-16 |
| 微雪 Bus Servo Adapter (A) | 1 | ✅ 到货 2026-10-09。即[电控采购清单](docs/电控采购清单.md)「半双工总线转接板」项；顶替 URT-2 上机、整机总线走它还是飞线的方案待测 |
| 黑色降压模块（XT60 端子） | 1 | ✅ 到货 2026-10-09。板上丝印 **7.2-16V**（照片识别，待万用表核）。⚠️ 若输入下限真是 7.2 V，2S 带载跌到 6.6 V 时会掉出稳压——清单要求下限 ≤ 6 V，用前先实测 |
| 转接线 | — | 📋 待确认（10-09 是否同批到货未记录，台架暂用 URT-2 + 飞线顶） |

---

## 飞特资料在哪

本地 `飞特-HD1910/` 只有规格书 PDF、DWG、STP。**软件和手册在 Gitee，不在官网**：

| 要什么 | 在哪 |
|---|---|
| **FD 调试软件** + **CH340 驱动** | **仓库里就有：[`tools/飞特/`](tools/飞特/)**（FD 1.9.8.5 + 驱动，MIT，带 sha256）。原始出处 [gitee.com/ftservo/fddebug](https://gitee.com/ftservo/fddebug) |
| 例程 / 通信协议 / 内存表 | [gitee.com/ftservo](https://gitee.com/ftservo) 各仓库 |
| 官网软件页（备用） | [feetech.cn/software.html](https://www.feetech.cn/software.html) |
| 入手教程 PDF | [先看这里-入手教程](https://www.feetech.cn/Data/feetechrc/upload/file/20220618/%E5%85%88%E7%9C%8B%E8%BF%99%E9%87%8C-%E5%85%A5%E6%89%8B%E6%95%99%E7%A8%8B2-1.pdf) |

---

## 舵机配置 · 拿到货一步一步做

**目标**：15 颗 HD-1910 每颗设好 ID、打开保护、贴上标签，装机时拿起来就知道它是哪个关节。

### 需要什么

| 东西 | 说明 |
|---|---|
| HD-1910-C001 × 15 | 出厂 ID **全是 1** |
| FE-URT-2 调试板 + USB-C 线 | 用左边两个白色 3 针口（丝印 `TTL-Bus`，`G V1 S`）。右边 4 针是 RS485，不用 |
| 一根剪开的舵机线 | 调试板的口跟舵机 2.0 mm 线**插不上**，得飞线。15 根牺牲一根 |
| 电源 | 三选一，见第 3 步。**只配 ID 的话 USB 就够** |
| 软件 | [`tools/飞特/`](tools/飞特/)：FD 1.9.8.5 + CH340 驱动，Windows |
| 万用表 | 量电压、查线序 |
| 标签纸 + 笔 | 第 7 步用 |

### 第 1 步 · 装软件

```
1  插上 URT-2 → 设备管理器「端口」里出现 USB-Enhanced-SERIAL CH343 (COMx)，记下号
   URT-2 是 CH343，Win10/11 自带驱动，不用装。没出现才装 tools/飞特/CH340_URT.rar（老款 URT-1 用）
2  解压 tools/飞特/FD1.9.8.5(250729).7z → 直接运行，不用安装
```

### 第 2 步 · 飞线

剪一根舵机线，一头是 2.0 插头、另一头三根裸线。**认脚号，别认颜色**：

```
舵机线                       URT-2
脚 1  Signal / TTL    →    S     焊到板背面白口 S 脚的焊点上（临时：线头镀锡后插进白口 S 孔）
脚 2  Vcc             →    V1    蓝色接线端子
脚 3  GND             →    G     蓝色接线端子
```

- **中间那根一定是 V**，飞特和 Dynamixel 在这点上一致 —— V 放错才会烧
- S 和 G 接反了**不会烧**，只是搜不到，对调即可
- 脚 1 在插头上有小三角或缺口标记，或看舵机本体插座旁丝印

### 第 3 步 · 供电

**URT-2 上那个拨码是 TTL 信号电平（3.3 / 5 V）选择，不是供电切换。** 拨 5 V（HD-1910 认 2–5 V，余量大）。
USB 插上时 V1 端子上有 5 V（实测 2026-09-12）。2026-09-17 查了厂家资料：URT-2 有两个接线端子，**V1 是 TTL 总线的外接电源输入，标称 DC 4.8–12 V**；V2 是 RS485 的，DC 12–24 V。URT-1 说明书的接线照片就是 USB 和外接电源同时接的。既然规格允许 12 V 进 V1，V1 和 USB 5 V 之间就不可能是直通，应该是二极管隔离，USB 单独插时才把 5 V 送到 V1。所以两种接法都行：

| 用什么 | 怎么接 | 什么时候用 |
|---|---|---|
| **USB 5 V** | 什么都不接，V1 自带 5 V | **配 ID、改参数**。HD-1910 从 4 V 起工作，空载够 |
| 可调开关电源 / 电池 → **V1 端子** | + 进 V1、− 进 G，舵机线直接插 TTL-Bus 口。厂家标准接法 | 15 颗一起，台架 |
| 可调开关电源 / 电池 → 舵机 | + 直接接舵机 V，− 接舵机 G **和** URT-2 的 G（共地），V1 空着 | 不想让电流过 URT-2 的端子和走线时（15 颗堵转能到十几安，端子标 6 A） |

⚠️ 别超 8.4 V，那是 HD-1910 的上限，不是 URT-2 的。

⚠️ **上电顺序：先插 USB，再给舵机上电。** 反了总线会被压在 2.1 V，一颗都不应答，见[踩坑记录 · 工具](踩坑记录.md#工具)。

**别在满电 8.4 V 的电池上做堵转测试** —— 那是 HD-1910 电压上限，零余量。

### 第 4 步 · 搜舵机

```
1  FD 里选第 1 步记下的 COM 口
2  波特率 1000000
3  点「打开」
4  只接一颗舵机（飞好线那根）
5  点「搜索」→ 列表里出现 ID 1，型号 HD-1910
```

搜不到，按顺序查：驱动装没装 → COM 口选对没 → 波特率是不是 1000000 → S 线接触好不好（临时插孔的最可疑）→ S/G 是不是反了。

### 第 5 步 · 改参数

切到「编程」页（EPROM）。**每颗都改这几项，别的别动：**

| 参数 | 出厂 | 改成 | 为什么 |
|---|---|---|---|
| **ID** | 1 | **按下表** | 官方运行时按这个 ID 找关节 |
| **过流保护** | 关 | **开** | 装机后堵转是常事，不开就是烧舵机 |
| **过压保护** | 关 | **开** | 8.4 V 满电落在 4–10 V 窗口内，不会误触发 |
| 过热保护 | 开（80 ℃） | 不动 | — |
| 波特率 | 1 Mbps | 不动 | 出厂就是官方要的 |
| 运行模式 | 模式 4 纯位置 PD | 不动 | 正是强化学习落地要的那个 |
| Return delay | 0 | 不动 | STS 系列上这项不起作用 |
| 中位 | — | **装机时再校** | 整机装完用调试台按官方折叠校（见第 9 步前「缩着能不能当标定基准」一节）。FD 的「中位校准」只会把当前位置当 2048，只能在腿伸直时用 |

改完点「保存」。

**ID 对照表** —— 来自上游 `duck-control/src/model.rs`，注释说数值是「对着硬件量出来的」：

| ID | 关节 | ID | 关节 | ID | 关节 |
|---|---|---|---|---|---|
| **10** | 右髋 yaw | **20** | 左髋 yaw | **30** | 颈俯仰 |
| **11** | 右髋 roll | **21** | 左髋 roll | **31** | 头俯仰 |
| **12** | 右髋 pitch | **22** | 左髋 pitch | **32** | 头 yaw |
| **13** | 右膝 | **23** | 左膝 | **33** | 头 roll |
| **14** | 右踝 | **24** | 左踝 | **34** | 嘴 |

**记法**：十位 = 部位（1 右腿 · 2 左腿 · 3 颈头），个位 = 从躯干往末端数（0 髋 yaw → 4 踝）。
ID 200 是 `imu_to_dxl` 板，固件里写死，不在这里配。

> 本机临时状态（2026-09-28）：原嘴 ID 34 的舵机已挪作 ID 21，用户确认 FD 中位校准到 2048；嘴位置暂缺。上表仍是设计 ID 分配，后续恢复总线前先核对实际在线 ID，不能直接按历史 15 颗全部在线启动动作。

### 第 6 步 · 验证

```
1  断电（拔 USB 或关电源）
2  重新上电
3  再点「搜索」→ 新 ID 出现了才算写进去了
```

这步别省，EPROM 参数要断电重启才确定。

### 第 7 步 · 贴标签，下一颗

标签写**关节名 + ID**（比如「左膝 23」），别只写数字。15 颗长得一模一样。
拔掉，换下一颗，回第 4 步。一颗约两分钟。

### 第 8 步 · 看它转（可选）

搜到舵机后在主页面点它，拉位置滑杆它就跟着转。USB 5 V 空载能转但没力；接了 7.4 V 才是真实工况。

### 2026-09-17 · 第一次整机上总线，记一个「缩起来」姿态

URT-2 + 网页调试台（`tools/servo-web/`）第一次把装好的鸭子 15 颗全读通：0 超时 0 校验错，7.2 V，30–40 °C。校零后扭矩全关、鸭子躺着让关节自然垂到底，读到的就是它「缩起来」的姿态，存在 `tools/servo-web/poses/缩起来-2026-09-17.json`：

| ID | 关节 | 舵机值 | 相对零位 |
|---|---|---|---|
| 20 | left_hip_yaw | 2084 | +3.2° |
| 21 | left_hip_roll | 1997 | -4.5° |
| 22 | left_hip_pitch | 772 | -112.1° |
| 23 | left_knee | 1058 | -87.0° |
| 24 | left_ankle | 2247 | +17.5° |
| 30 | neck_pitch | 1473 | -50.5° |
| 31 | head_pitch | 1094 | -83.8° |
| 32 | head_yaw | 2059 | +1.0° |
| 33 | head_roll | 2012 | -3.2° |
| 34 | mouth | 2047 | -0.1° |
| 10 | right_hip_yaw | 2018 | -2.6° |
| 11 | right_hip_roll | 2109 | +5.4° |
| 12 | right_hip_pitch | 3195 | +100.8° |
| 13 | right_knee | 3032 | +86.5° |
| 14 | right_ankle | 1782 | -23.4° |

看得出来的两件事：左右腿的髋 pitch、膝是镜像的（左 −112° / −87°，右 +101° / +87°），跟 MJCF 里左右腿正方向相反的约定一致；颈 −50°、头 −84° 是头垂到胸前。这套数以后可以当"收纳姿态"直接发。

### 2026-09-18 · 从缩起来到站姿怎么动（官方模型正解）

用 `tools/servo-web/model/model.json`（微调过的官方 MJCF）做正解，条件：脚底前后不倾、脚底点前后位置跟官方站姿一样。结果是一条直线：**髋 = −26° + 膝/2，踝 = +26° + 膝/2**（左腿；右腿全部反号，模型约定）。腿太短（大腿 42 mm、小腿 49 mm），膝弯到 +60° 躯干也只降 3 cm。

| 膝（模型约定） | 髋 | 踝 | 躯干比站姿 |
|---|---|---|---|
| −60° | −56° | −4° | 高 10 mm |
| 0° | −26° | +26° | 0（官方站姿） |
| +30° | −10° | +40° | 低 16 mm |
| +60° | +6° | +54° | 低 33 mm |

**重心（用官方 robot_walk.xml 的质量）**：整机 744 g，脚底在脚 site 前 34 mm、后 20 mm。站姿时重心投影离脚尖 34 mm、离脚跟 20 mm；半蹲（膝 +60）到站姿整条路余量都在 17 mm 以上；头颈每 10° 重心只挪 2.4 mm；髋每多前倾 5°（踝反向 5° 保持脚平）脚往前挪、脚尖余量 +5 mm。按模型，慢慢站不该往前倒，真机倒了先查零位偏差（右髋 27°、左踝 28°）和电池装没装。页面 3D 里现在实时画重心投影（绿点 + 虚线）和两脚支撑区，出了支撑区变红，右下角报四个方向的余量。

**真机方向跟模型不一样的关节要用页面上的 ± 翻**：2026-09-18 对着缩起来的照片核，膝（23、13）、颈 pitch（30）、头 pitch（31）是反的，踝待验。序列文件里写的是模型约定的相对角度，页面发之前按 ± 换算。

从缩起来（髋 −112 / 膝 −87 / 踝 +17）站起来的顺序，做成了页面上的序列「站起来」（`poses/站起来-序列.json`）：

1. 抬头 1 s：颈、头 pitch 到 +20°。头占整机三分之一重量，趁身子还坐在桌上先摆到站姿位置。
2. 展腿脚放平 3 s：以实机站姿为基准，膝 +60 / 髋 +30 / 踝 +30（模型约定，左腿；右腿反号）。脚从身后翻到身下踩住桌面，身体被顶起约 9 cm，这一步最关键，第一次托着做。
3. 站直 2 s：沿脚平那条线到官方站姿。三个角同时线性变，脚全程平，身高只涨 10 mm。

页面加了「过渡时间」：所有姿态、站姿、回零位都从当前实际位置线性插过去，20 Hz 发同步写，不再一下跳。前提是舵机方向跟模型一致（待查 8），先单颗试 22 号往负方向是不是大腿往前抬。

### 2026-09-22 · 缩着能不能当标定基准（官方模型精确网格求交）

群里的讨论：官方零位是腿伸直，悬空手扶着摆没有参考点，一两度就摔；能不能拿缩着当基准。用官方模型把每个腿关节往折叠方向转到零件碰上（fcl 精确网格，不用凸包，[`tools/fold_contact`](tools/fold_contact/)）：

- 顶住关节的**都是脚和踝**，不是关节自己的限位，所以停在哪跟别的关节有关：膝在髋 0° 时 70.7° 碰上，髋 90° 时 89.6° 碰上
- **踝缩着时没被定住**，膝和髋都折到底后还有约 20° 能动，缩着校不了踝
- 官方 FOLD（髋、膝 ±90°）的膝几乎就是接触点，1.57 rad（89.95°）会让踝顶进大腿舵机约 0.36°（接触在 89.59°）；9/20 存的「缩」左膝换算约 88°，跟这个接触点对得上
- FOLD 的颈 / 头 pitch 是 57°，**不是接触点**：腿折好后颈要转到 66.6° 颈舵机才碰上躯干外壳，57° 前后都空着
- 这是 XL330 原版几何，飞特版改过 8 个件，要拿飞特版模型再算或在 SolidWorks 里量

分析结论：缩着只能当髋、膝的参考，而且摆法要写死。零点仍然是官方的 2048，官方代码和策略不用加补偿 —— 缩着只是参考点，不是新零点。

**最后定的做法**（调试台 0.14.0 起的基准「官方折叠（头颈摆正）」，0.15.0 按审查修过）：

- 腿按官方 FOLD 摆：膝折到踝刚贴上大腿舵机（零件顶住，每次都一样），髋 pitch 用直角尺摆到跟躯干垂直，髋 yaw / roll、踝 0°
- 头颈不按官方 FOLD 的 57°（不是接触点、靠眼睛摆不准），改成摆正：脖子竖直、头平视，嘴闭上
- **15 颗一起标**，扭矩关着用手摆。目标：± 全 −1 时 22 / 23 = 1025、12 / 13 = 3071，其余 2048；写进舵机 EEPROM（0x0B 带目标值 = 「当前位置就是这个读数」），零点照样是官方的 2048
- 膝按官方 1.57 rad 算，实际摆到接触点 89.59°，零点差约 0.36°（4 步），忽略
- 确认框逐颗列「现在 → 写成、差几度」；差 30° 以上再确认一次，**不拦**：装舵盘时转了半圈会差 180°，校准正好纠回来；方向 ± 设反了也差 180° 左右，那样校进去是错的，先用手掰一下看 3D 转向核 ±
- 校完扭矩还是关着，用手展开再开扭矩不会跳（0.15.0 起开扭矩前先把目标对准当前位置）

### 第 9 步 · 装机、归零、试行程

**零点是什么**：机器人**笔直站立**的姿态 —— 腿是直的柱子、脚平放、脖子竖直、头平视。这是 MJCF 里所有关节 = 0 的位置，对应舵机 **2048**。

**站姿不是零点。** 官方站立姿态（`DEFAULT_POSITION`）是从零点加的偏移：髋 pitch ±26°、踝 ∓26°、颈和头 pitch +20°。这是软件的事，**别把站姿校成 2048**。

**每个关节的做法**：

```
1  舵机 FD 里先转到 2048，再装舵盘（舵盘齿位对不准就近，误差归下一步）
2  把关节摆到「直」的位置，用手扶着
3  FD 编程页 →「中位校准」→ 当前位置定义为 2048（或 `tools/servo-web/` 网页调试台的「中位校准」按钮，装好以后用手扶直再点，同一个指令）
4  锁紧螺丝
5  FD 从 2048 慢慢拉到下表的上下限，看结构件碰不碰、线扯不扯
6  碰了记下那颗的实际角度 —— 比软件限位小是正常的，那才是这台机器的真实行程
```

**行程表** —— 来自 MJCF `robot_walk.xml` 的 `range`，这是**软件限位**，机械上能不能到要试。HD-1910 是 4096 步 / 360°，1° ≈ 11.4 步：

| ID | 关节 | 行程 | 舵机值（2048 为零） |
|---|---|---|---|
| 10 / 20 | 髋 yaw | 右 −30 ~ +25°　左 −25 ~ +30° | 右 1707 ~ 2332　左 1764 ~ 2389 |
| 11 / 21 | 髋 roll | ±22° | 1798 ~ 2298 |
| 12 / 22 | 髋 pitch | ±90° | 1024 ~ 3072 |
| 13 / 23 | 膝 | ±90° | 1024 ~ 3072 |
| 14 / 24 | 踝 | ±90° | 1024 ~ 3072 |
| 30 | 颈 pitch | −90 ~ +60° | 1024 ~ 2731 |
| 31 | 头 pitch | ±90° | 1024 ~ 3072 |
| 32 | 头 yaw | ±170° | 114 ~ 3982 |
| 33 | 头 roll | ±25° | 1764 ~ 2332 |
| 34 | 嘴 | −5°（闭）~ +30°（开） | 1991 ~ 2389 |

髋 yaw 左右不对称是镜像 —— 两条腿往外转 30°、往内转 25°。嘴不在 MJCF 里（策略不控制它），范围来自 `model.rs` 的 `MOUTH_CLOSED / MOUTH_OPEN`。

⚠️ **正负方向哪边是哪边，跟舵机装的朝向有关**，官方运行时里每颗有方向和偏移量（`motor.rs`，注释说是「对着硬件量的」）。试干涉的时候两个方向都拉到底就行，不用管符号。

---

---

## 不打 HAT · 飞线接主控

**单独成文了 → [docs/不打HAT.md](docs/不打HAT.md)**。很多人觉得 HAT 打样太贵，那份就是替代方案：¥70 的模块、一步一步接、哪步会烧东西。
这里只记做的时候发生了什么。

---

## 2026-09-10 · 舵机和调试板到了

**到了什么**：15 颗 HD-1910-C001，一块 FE-URT-2 调试板（USB-C，TTL 和 RS485 口都有）。

**第一个问题**：舵机原装线是 **2.0 mm 3P**（规格书写的 AMP2.0-3P），调试板左边那两个白色 TTL 口**比这个大，插不上**。板子没给 2.0 的口。

**怎么办**：买「舵机转接线 2.0 转 2.5 3P」。等线的期间要动手就剪两根线对焊。
`imu_to_dxl` 板的 J4/J5 是 PH 2.0 mm，跟舵机线是配的，**不受影响** —— 只是这块调试板的口不对。

**下一步**：转接线到了逐个配 ID。**一次只接一颗**（出厂 ID 全是 1），改完贴标签。
顺手把每颗的过流、过压保护打开（出厂默认关）。波特率和运行模式出厂就是对的，不动。
步骤和 ID 表见上面 [舵机配置 · 拿到货一步一步做](#舵机配置--拿到货一步一步做)。

---

## 2026-09-12 · 器件到齐，主控排针焊好，舵机开始装机械件

**到了什么**：Radxa Zero 3W（2 GB 裸板）、ToF、电池、电池仓、microSD、排针、摄像头。加上 09-10 的舵机和调试板，**除了 `imu_to_dxl` 板（立创还在做）和飞线模块（降压、转接板、转接线），全齐了**。

**做了什么**：
- 2×20 排针焊到 Radxa 上了
- 开始把飞特 HD-1910 往机械件里装

**发现的问题**：**HD-1910 跟原版 XL330 在结构上有差异**（压腿那一处）。同事改了结构件重新打印，改后能装。
具体哪个件、改了哪里、改了多少 —— *待补*（拍照、量尺寸，写进 [构建日志](构建日志.md)，同时在 [执行器选型](docs/执行器选型.md) 的 HD-1910 那节加一条「机械上不是直接替换，要改件」）。

**算法侧发来训练前数据采集清单** → 填好的在 [docs/HD-1910训练前数据清单.md](docs/HD-1910训练前数据清单.md)，仓库有的全填了，台架项标了怎么测。

**下一步**：
- 舵机继续装，装完一条腿先量一次活动范围
- 配 ID —— 转接线还没到，先按 [上面第 2 步](#第-2-步--飞线) 剪一根舵机线飞过去。**今天先做这个**
  - ✅ 线飞好了，拨码拨到 USB 侧，G–V1 量到 5 V
  - ✅ 插电脑出 **COM5**，芯片是 **CH343**（不是 CH340），Win 自带驱动直接认 —— 手册第 1 步已改
- 主控刷机 —— **没读卡器，做不了**。卡是 microSD，板子自己不能当读卡器用；笔记本没 SD 槽的话得买一个（USB 3.0 的）。到了按 [不打 HAT · 第 1 步](docs/不打HAT.md#第-1-步--主控点亮什么都别接) 点亮

---

## 2026-09-13 · 15 颗全配完、全装上，开始台架

**做了什么**：15 颗 HD-1910 全部配好 ID、开了过流过压保护、装进机身。

**台架接法**（不用降压模块，Radxa 用充电头）：
- 可调电源 7.4 V 限 2 A → **直接接舵机总线 V/G**，URT-2 的 G 也接电源负极共地，**V1 端子空着**
- URT-2 拨码 = 信号电平，拨 5 V（之前写的「外接侧」是错的，那板子没有供电切换）
- URT-2 USB-C → Radxa **host** 口（不是电源口）
- Radxa 电源口 → 5V/2A 充电头（**别用电脑 USB，500 mA 不够**）

**下一步**：`dmesg` 看 CH343 出没出 `ttyACM0` → Python 扫 ID 10–34 → 15 颗全应答 → 官方运行时。

---

## 2026-09-16 · 主板上电，烧卡

**做了什么**：
- Radxa Zero 3W 裸板上电，正常。排针 2.54 mm，跟 DXF 里的孔距对上（两排 y = 25.41 / 27.95 mm）。
- 读卡器、5 V 降压模块到了。
- 烧 Armbian 26.8.1 trixie minimal（sha256 校验过）。Rufus 便携版，认 `.img.xz`，2 分钟写完。截图在 [`assets/flash/`](assets/flash/)，步骤写进了 [不打 HAT · 第 1 步](docs/不打HAT.md#第-1-步--主控点亮什么都别接)。

**踩的坑**：想用 `wsl --mount` 把 `.not_logged_in_yet` 写进烧好的卡，报 `ERROR_FILE_NOT_FOUND`，WSL 挂不上 USB 读卡器。改成**先把预设塞进镜像再烧**，脚本放在 [`tools/radxa/`](tools/radxa/)，不用管理员。记在 [踩坑记录](踩坑记录.md)。

**瑞莎资料**：原理图 / 产品简介 / 2D DXF / 3D STP / 元件位置图都下了，本地 `Radxa-Zero3W/`。**没有 PCB 源文件**，位置图和 DXF 里也没标 pin 1。认 pin 1 靠万用表：OTG 口供电，量排针四个角，3.3 V 那个是 pin 1，它旁边 5 V 的是 pin 2。

**下一步**：卡插上开机 → 路由器里找 `radxa-zero3` → `ssh duck@IP` → 插 URT-2 看 `dmesg`。

---

## 2026-09-16 ～ 17 · 主板点亮，九张卡

**结果**：Armbian 26.2.1 vendor 在板上跑起来了，WiFi 自动连、ssh 能进、`/dev/ttyS2` 出来了、插电脑多一个 USB 串口，Pollen 官方三个脚本跑完，daemon 0.13.0 装上。做卡一键化在 [`tools/radxa/`](tools/radxa/)。

**过程**（按时间）：
- 09-16 晚：Rufus 烧 Armbian 26.8.1，WiFi 预设塞进镜像。开机灯双闪，局域网里没有它。以为是 WiFi：路由器 WPA3 混合、AIC8800 不支持 GCMP-256、5G 频段、两套驱动打架，一版版改，烧了四次，都没有。
- USB 串口这条路也试了：`g_serial` + `dwc3-peripheral`，电脑看不见设备。
- 读卡：把卡的根分区拷出来挂上看，**根分区一个字节没被写过**，首次开机标记还在，分区没扩容。也就是内核起了心跳但从没挂上系统盘。前面改 WiFi 的四版全是无用功，问题在更前面。
- 换底子到 26.2.1（官方指定版本）、去掉 SDR104，都不行。做了「黑匣子」initramfs（进 initramfs 灯灭、找到盘常亮、失败快闪、内核日志写到卡的分区外区域），结果灯一直双闪，连 initramfs 都没进。
- 09-17 零点：瑞莎官方镜像（b1，2025-07）烧上，同一张卡同一块板，两分钟连上 WiFi。ssh 进去看：SD 卡跑 SDR104 正常，WiFi 是 AIC8800D80/DS2，设备树跟 Armbian 的逐项比对基本一样。板子、卡、供电、设备树全排除。
- 比引导程序：Armbian 用主线 U-Boot 2025.10 + DDR 固件 v1.21（2024-01），瑞莎用 rk U-Boot 2017.09-51 + DDR v1.23（2024-09）+ BL31 v1.45。板子是 2024-11 的 V1.12。
- 把瑞莎镜像的扇区 64～32767（idbloader + u-boot.itb）覆盖到 Armbian 卡上，加一个 `/boot/extlinux/extlinux.conf`，**第九张卡起来了**。灯：双闪 → 灭 → 常亮，局域网里 `192.168.0.102`，电脑上多了 COM5。
- 然后按官方 `install-by-hand.md`：extlinux 挂 `uart2-m0` + `dwc3-peripheral`、控制台放 tty1、mask 掉 ttyS2/ttyFIQ0 的 getty；WiFi 改成 Armbian 标准 netplan 写法；`setup-board.sh`（aic3x 编解码器 DKMS、ONNX Runtime 1.28、ToF udev 规则）→ `migrate-network.sh`（NetworkManager）→ 重启 → 再各跑一次 → `install.sh`（daemon 0.13.0）。板子走电脑的 Clash 代理下 GitHub。

**踩的坑**都进了[踩坑记录](踩坑记录.md)：引导程序、GCMP-256、dwc3-peripheral、GitHub 代理、首次开机预设缺变量。

**下一步**：第 4 步舵机总线接主控（URT-2 走 USB，或飞线到 pin 8/10 用 `/dev/ttyS2`），`robotctl health` 看 15 颗舵机。

**躯干 IMU 两条路线**（2026-09-17 定下来并行）：

| | A · `imu_to_dxl` 小板 | B · GY-BNO085 模块直飞主板 |
|---|---|---|
| 硬件 | 自绘板，已到货，3.3 V 正常，连接器封装待改 | ¥66 现成模块，I2C 接 40 针 pin 3/5（跟 ToF 同一条 i2c3），3.3 V 取 pin 1 |
| 软件要做的 | STM32 固件：ID 200 寄存器协议 + IMU 融合，**目前没有公开固件，从零写** | robotd 里加一个 I2C IMU 源（Rust），BNO085 片内融合直接出四元数 |
| 对官方运行时 | 协议兼容，robotd 不改 | robotd 改 IMU 后端 |
| 共同要做 | 飞特舵机协议移植（robotd 说的是 Dynamixel） | 同左 |

原型机时代（树莓派 Zero 2 W 版）就是 I2C 接 BNO055，B 路线有先例。先买一块，`i2cdetect -y 3` 看到 0x4A、Python 读出四元数就算通。

---

## 2026-09-28 · HAT 到货、替换 ID 21、摄像头终于出图

**舵机**：用户将原嘴 ID 34 的舵机挪作 ID 21，替换损坏的原 21，并用 FD 完成 2048 中位校准。此项来自用户确认；本轮主板/摄像头检查没有重新读回舵机寄存器，也没有执行动作。嘴暂缺，设计 ID 表不变。

**主板与供电**：HAT 已与主板对插，用户从可调电源向 HAT 输入 7.4V，开始逐项检查。HAT 的降压输出给主板 5V；主板联网后通过 Wi-Fi / SSH 调试。主板的 `5V IN / USB_OTG` 兼有供电和 gadget 功能，USB 3.0 是 Host；HAT 供电时不要同时用普通 USB 数据线接电脑引入第二路 5V。此处记录接法与调试进展，不代表负载、电压纹波、音频或舵机总线已经验收。

**摄像头过程**：

1. 原 Armbian 下相机不应答，IMX219 寄存器读取报错，媒体拓扑中没有传感器实体。
2. 换瑞莎官方 Bookworm KDE B1 做对照；镜像只预置本机 Wi-Fi / SSH，内核、驱动及系统内容保留原版。启动后通过官方 `rsetup` 启用 `radxa-zero3-radxa-camera-8m.dtbo` 并重启。
3. 官方系统起初仍复现 `Error -5`；不能仅凭有 `/dev/video0` 就判相机正常。绿灯双闪是该系统的 `heartbeat`，不是启动失败证据。
4. 用户检查并调整排线正反面后重新上电，成功读到 `Model ID 0x0219`，`imx219` 驱动绑定，媒体链路完整。
5. GStreamer 限量采集 40 帧，约 4.05 秒后正常 EOS、退出码 0；实际查看最后一帧，1920×1080 JPEG 中可见天花板、灯和显示器。

接线参考图、完整复测命令、版本和证据见 **[摄像头调试记录](tools/radxa/摄像头调试记录-20260928.md)**；精简提醒见 **[踩坑记录](踩坑记录.md#主板--hat--摄像头)**。

**后续顺序**：用户已决定换回原项目 Armbian，保持成功接法先复测识别和抓帧，再恢复项目运行环境、测试持续视频，之后逐项验 HAT 外设和舵机总线。此前带 Wi-Fi 的 09-20 基础镜像已做只读文件系统检查，通过；本轮末尾已正常关机，等待断电取卡烧录。该镜像不是刷官方卡前的完整运行卡备份，摄像头启用与项目软件需恢复。原 Armbian 未在正确接线下复测；相机出图不等于整机、HAT 供电路径或行走已验收。此前建议的“拆 HAT、主板单独 USB 供电”是否实际执行未确认，不把它算作已完成测试。

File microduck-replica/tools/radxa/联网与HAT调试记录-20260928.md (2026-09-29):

# 2026-09-28：DHCP 修复与 HAT 舵机只读实测

本记录的日期以调试电脑为准；主板系统时间尚未确认同步，不使用其日志时间推断实际日期。

## 联网结论

此前 9 月 20 日镜像配置了 `wpa_supplicant` 无线认证，但默认 netplan 仅匹配有线接口，没有给 `wlan0` 配置 DHCP。修复为新增 `/etc/systemd/network/25-wlan0.network`：

```ini
[Match]
Name=wlan0

[Network]
DHCP=ipv4
```

在本机个人镜像上实测：

- 成功通过 WiFi SSH 登录，主机名为 `radxa-zero3`。
- 系统为 Armbian 26.2.1 Trixie，内核 `6.1.115-vendor-rk35xx`。
- `networkctl status wlan0` 显示 `Network File: /etc/systemd/network/25-wlan0.network`，状态 `routable (configured)` / `online`，取得 DHCPv4 地址和默认路由。
- `systemd-networkd` 和 `wpa_supplicant@wlan0` 为 active；NetworkManager 未启用；`systemctl --failed` 无失败服务。
- 首次检查时启动约 6 分钟，CPU 温度约 56℃。内核日志仍有显示/GPU、以太网及启动阶段 SD 调谐等告警，不能把“能 SSH”当作全部硬件均无问题。

这证明本次修复在当前主板及无线环境中生效。未做多次冷启动和其他路由器兼容测试，不能宣称所有联网问题都已解决。公开 Release 的旧 `.img.xz` 和校验值没有替换，用户仍需按[使用说明](镜像使用说明.md#4-连-wifi)补配置。

## HAT 串口测试

主板 `/dev/ttyS2` 存在，无进程占用；`serial-getty@ttyS2` 和 `serial-getty@ttyFIQ0` 均被 mask。通过 HAT 以 **1,000,000 baud** 进行测试，只允许协议 `PING` / `READ`，没有发送写寄存器、开启扭矩、校准或运动指令。

首次读取：13 颗舵机成功响应；23 号、34 号没有响应。全 ID 扫描和后续复查表明：

- 关节 ID `10–14`、`20–24`、`30–33` 均有响应，共 14 颗。
- 用户确认嘴部已从 34 改为 29，因此 34 不响应是预期；29 仅识别到固件/型号字段后即停止进一步测试。
- 23 号左膝存在间歇无应答，不能按首次扫描结果认定损坏或未接线。

连续 20 轮对上述 14 颗关节舵机逐个读取反馈寄存器 `56–70`：

| 对象 | 成功 / 次数 | 观察 |
|---|---|---|
| 23 号左膝 | 18 / 20 | 2 次没有收到帧头，成功响应的状态码为 0 |
| 其余 13 颗关节舵机 | 各 20 / 20 | 状态码均为 0，无校验错误或 ID 错误 |

读取期间电压约 7.4–7.5V，温度约 30–33℃。寄存器快照中，14 颗关节舵机扭矩开关均为 0，状态位为 0，运行模式为 4。这里是短时只读通讯检查，不是带载或运动稳定性测试。

## 运动前待处理

1. **23 号的间歇通讯问题。** 先正常关机并断开 HAT 输入后检查该舵机的插头、线缆和供电连接，再复测；必要时与已正常通讯的线缆/接口对照。现有数据不能单独确定是线缆、接触、设备还是总线时序问题。
2. **卸载保护配置。** 读到的 14 颗关节舵机寄存器 19 均为 `4`。按仓库飞特内存表，它仅设置过热保护位，未设置电压、过流和过载卸载位；本次只读取，没有修改。阈值也需结合具体型号核对，不能仅打开开关就视为保护验收通过。
3. **回零姿态与机械范围。** 数值 2048 是否对应每个关节的安全装配零位还需逐关节确认；校准偏移大不能仅凭数值判定装配错误。保护与通讯确认后，再在机体有支撑的条件下做低速、小范围验证。
4. **其他功能。** 本次 Armbian 启动没有出现 `/dev/video*`，摄像头配置/复测仍待处理。本次没有运行策略模型或机器人动作。

## 主板上的 WiFi 调试网页

随后已将 `servo-web` 0.15.2 部署到主板 `/home/duck/servo-web`，启动手动服务 `microduck-servo-web`，浏览器通过 `http://主板IP:8080/` 访问。已验证首页、模型资源、`/api/info` 和 WebSocket 实时数据正常，`fake=false`、串口为 `/dev/ttyS2`。这次启动扫描得到 13 颗；23 号当时没有响应，因此未加入自动轮询，不能把其余 13 颗的正常轮询当成 23 号已恢复。

启动参数管理 `20–24`、`30–33`、`10–14`，按用户要求排除嘴部 29。服务未启用开机自启；此为主板上的单独部署，没有打包进公开基础镜像。操作命令：

```bash
sudo systemctl status microduck-servo-web --no-pager
sudo systemctl stop microduck-servo-web   # 改用其他总线测试工具前先停
sudo systemctl start microduck-servo-web  # 主板重启后需要时手动启动
```

部署前修正了调试台连接串口时自动放开速度/加速度限制的行为；0.15.2 启动只扫描、读相位，不写运动设置。协议模拟器的回归测试和自检均通过。网页仍有实体运动和校准按钮，不是功能受限的只读页面；本次验收仅访问页面及读取状态，没有触发这些按钮。

原始只读寄存器快照和连续读取统计已保存在调试电脑的 `Radxa-Zero3W/调试记录/`。实测结果只覆盖本文列出的设备和操作。

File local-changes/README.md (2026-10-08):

# local-changes —— 从参考库提取的本地修改

2026-10-09 按「参考库只读」规则，把此前混入参考目录的本地修改提取到这里，三个参考目录已还原为上游原样（逐文件哈希校验记录见根目录 [PROGRESS.md](../PROGRESS.md)）。

**这里只是存档，不是可运行工程。** 如需恢复 A 训练环境，把对应文件按相对路径复制回 `microduck-build-tutorial/` 即可；注意 `export_onnx.py` 内硬编码的 `/mnt/e/` 路径与 WSL venv 路径是 E 盘时代写的，工程已迁到 `C:\Projects\duck-robot`，复用前必须先改。

## microduck-replica/

- `调试记录.md`：上游版 + 7 行本地到货记录（2026-10-09 会话误写入上游文档）。用户相关内容已转录到根 PROGRESS.md「2026-10-09 硬件到位」；此份仅作原样留存。

## microduck-build-tutorial/

A 训练重建时的库内修改（背景见根 README「方案 A」一节与 [docs/a-training.md](../docs/a-training.md)）：

| 文件 | 性质 |
|---|---|
| `mjlab_microduck/.gitignore` | 修改：放开 `uv.lock` 版本化、忽略项从 `xxx/*` 改 `xxx/` |
| `mjlab_microduck/pyproject.toml` | 修改：依赖版本钉死（torch 2.9.1 / mujoco 3.10.0 / BAM rev 锁定等） |
| `mjlab_microduck/src/mjlab_microduck/scripts/export_onnx.py` | 重写：安全导出（显式 checkpoint/output、奇偶校验），含 `/mnt/e/` 硬编码路径 |
| `mjlab_microduck/src/mjlab_microduck/tasks/microduck_velocity_env_cfg.py` | 修改：命令课程按 dataclass 重建、reset 高度、3000/6000 iteration 速度扩展等 |
| `mjlab_microduck/README.md`、`mjlab_microduck/scripts/validate_contract.py` | 新增：A 训练说明与 51/14 合同检查脚本 |
| `mjlab_microduck/uv.lock` | 新增：钉死环境的锁文件 |
| `mjlab_microduck/src/mjlab_microduck/robot/`（49 文件） | 新增：官方 [pollen-robotics/microduck_rl](https://github.com/pollen-robotics/microduck_rl) @ `cb70b792312d559a4da09064d92009079671815f` 的模型恢复树，含 `source_manifest.json` 与 `provenance/` 溯源 |

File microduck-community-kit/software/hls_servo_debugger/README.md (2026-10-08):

# HLS 舵机浏览器调试工具

这是一个面向飞特 HLS 系列串行总线舵机的浏览器调试软件，放在
`microduck-community-kit/software/hls_servo_debugger` 下。后端使用 Python + Flask + pyserial，
前端为纯 HTML/CSS/JavaScript，无需前端构建工具。

工具以 `FTServo_Linux-main/src/HLSCL.cpp`、`SCS.cpp` 和官方
《磁编码 HLS 舵机-内存表解析》为依据，覆盖 HLS 舵机的指令、内存表、控制模式、
同步读写和原始协议调试。

## 功能范围

- 串口连接：`/dev/ttyACM1` 等设备选择、常用波特率、超时设置、自动探测 ID1。
- **整机 15 台舵机初始化**：按 microduck 的关节表逐个把出厂舵机（ID 1）编号成
  20~24 / 30~34 / 10~14，并按选择的工艺做初始位置校准、回读校验和写入锁保护；
  15 台列表按 ID 升序显示，点检后在线的点黄、本页已完成的显示绿；
  另有 9/11 号多圈开关（默认关闭）、19 号电压/过流保护开关（默认关闭）。
  见下文《整机 15 台舵机初始化》。
- PING / 扫描：单个 Ping、按 ID 范围扫描、可读取版本。
- 实时反馈：一次读取 56~70 共 15 字节，显示位置/速度/负载/电压/温度/状态/移动/目标位置/电流，并绘制趋势图。
- 位置控制：位置伺服模式、扭矩开关、目标位置、速度、加速度、目标电流、转矩限制、角度限制、异步写（REG_WRITE）+ REG_ACTION、中位校准（可选 CAL 后保存到 EPROM 并重新上锁）。
- 速度/电流/PWM：恒速模式、恒流模式、PWM 开环模式，以及对应写入方法。
- 参数配置：按 HLS 内存表自动生成 0~86 字段的读取/写入界面，支持枚举、位域、正负号字段编码；
  回读值列只显示可读懂的结果（计数 + 工程量 / 枚举名 / 打开的位名），原始字节放在悬停提示里。
- 同步读写：SYNC_READ(0x82)、SYNC_WRITE(0x83)、同步位置写、同步速度写。
- 高级调试：任意地址/长度 READ/WRITE、REG_WRITE、REG_ACTION、RESET、RECOVERY、CAL、写锁控制、原始十六进制帧收发。
- 日志：显示 TX/RX/错误帧，便于核对校验和和异常。
- 内存表参考：完整字段、地址、范围、单位、方向位说明。

HLS 参考库中的 `WritePosEx`、`RegWritePosEx`、`SyncWritePosEx`、
`SyncWriteSpe`、`ServoMode`、`WheelMode`、`EleMode`、`WriteSpe`、
`WriteEle`、`EnableTorque`、`unLockEprom`、`LockEprom`、
`CalibrationOfs`、`FeedBack`、`ReadPos/ReadSpeed/...` 均有对应前端操作或
API 入口。

## 目录结构

```text
hls_servo_debugger/
├── pyproject.toml
├── README.md
├── run.sh
├── hls_debugger/
│   ├── __init__.py
│   ├── __main__.py
│   ├── protocol.py        # FT-SCS/HLS 协议、串口收发、同步读写、应用层指令
│   ├── memory_table.py    # HLS 内存表、数据编解码、反馈解码
│   ├── provision.py       # microduck 15 个关节表 + 初始化（编号/校准）流程
│   ├── server.py          # Flask API 和 Web 服务入口
│   └── selftest.py        # 无硬件协议自检（含从站模拟，可离线跑完整初始化流程）
│   └── static/
│       ├── index.html
│       ├── style.css
│       └── app.js
├── hw_test.py             # 真机只读连通性测试（PING/READ，不产生动作）
└── .venv/                 # uv 创建的虚拟环境（本地生成）
```

## 安装与运行

### 方式一：使用 `run.sh`

```bash
cd microduck-community-kit/software/hls_servo_debugger
./run.sh
```

脚本会自动用 `uv` 创建 `.venv` 并安装 Flask、pyserial，然后启动服务。

### 方式二：手动使用 uv

```bash
cd microduck-community-kit/software/hls_servo_debugger

uv venv .venv --python python3
uv pip install 'Flask>=2.2,<3.0' 'pyserial>=3.5'

uv python -m hls_debugger
```

启动后浏览器访问：

```text
http://127.0.0.1:8765/
```

默认会自动打开浏览器；使用 `--no-browser` 可禁止自动打开：

```bash
.venv/bin/python -m hls_debugger --no-browser --port 8765
```

### 方式三：直接跑在机器鸭核心板上（推荐，见下文《部署到核心板》）

核心板上没有 `uv`，依赖用 apt 装（`python3-flask` / `python3-serial`），
`run.sh` 会自动退回系统 Python，并把默认串口设成 `/dev/ttyS2`：

```bash
ssh root@<板子> 'cd /opt/hls_servo_debugger && ./run.sh --host 0.0.0.0'
```

然后在同一局域网的电脑上开 `http://<板子IP>:8765/`。

## 部署到核心板（radxa-zero3）

这块板子的事实（2026-10-05 实测）：`root@192.168.124.4`、Armbian 26.8.1（Ubuntu 26.04）、
**Python 3.14**、**没有 `uv` 也没有 `pip`**、apt 能连上 `ports.ubuntu.com`；
舵机与 `imu_to_dxl` 小板共用 **`/dev/ttyS2`**（`/etc/robot/robotd.toml` 的 `bus.port`），
平时由 `robotd` 持有。

```bash
# 1) 依赖：用发行版的包，不碰 pip（板子上没有，也没有 PyPI 直连）
ssh root@<板子> 'apt-get update && apt-get install -y python3-flask python3-serial'
ssh root@<板子> 'python3 -c "import flask, serial; print(flask.__version__, serial.__version__)"'

# 2) 拷源码（.venv 是本机的 x86_64 环境，不要拷）
rsync -av --delete --exclude '.venv' --exclude '__pycache__' \
      software/hls_servo_debugger/ root@<板子>:/opt/hls_servo_debugger/

# 3) 用的时候手动起（前台跑，Ctrl-C 就停；没有 systemd 单元，也别做成开机自启）
ssh root@<板子> 'systemctl stop robotd'                    # 让出总线
ssh root@<板子> 'cd /opt/hls_servo_debugger && ./run.sh --host 0.0.0.0 --no-browser'
#    浏览器开 http://192.168.124.4:8765/  →「连接与扫描」选 /dev/ttyS2、1 Mbps →「点检 15 台」
# 4) 用完了：Ctrl-C 停掉它，再把总线还给 robotd
ssh root@<板子> 'systemctl start robotd'
```

**它故意不做成系统服务。**这是台面/标定用的工具，用完就该关：它和 robotd 抢同一根串口，
常开着只会制造"两个进程互吃应答帧"的机会。想让它在你退出 SSH 后继续跑就用 `tmux`/`nohup`，
但记住用完要收掉。

几条要注意的：

* **停 `robotd` 不会切扭矩**，机器人保持当前姿态；但这时没有任何人在平衡，别在它站着的时候
  去拧关节。
* **一次只让一个进程持有串口。** `robotd` 的 `TIOCEXCL` **拦不住 root**（实测：两个 root 进程
  能同时打开 `/dev/ttyS2`），所以本工具在连接前会扫 `/proc/<pid>/fd`，发现别人占着就返回
  `409 port_busy` 并点名（`robotd (pid 975)`）。`fuser -v /dev/ttyS2` 也能看是谁拿着。
* `--host 0.0.0.0`：**任何能连到板子的人都能给舵机写寄存器**，只在可信任的局域网里开。
* 自检（不需要硬件，也不需要 robotd 停）：`ssh root@<板子> 'cd /opt/hls_servo_debugger && python3 -m hls_debugger.selftest'`
  ——板子上没有 Rust 源码，与 `feetech.rs` 对拍的那条用例会自动跳过。

## 快速上手

1. 给舵机接好电源和串口总线，确认设备确实是 `/dev/ttyACM1`（核心板上是 `/dev/ttyS2`）。
2. 打开页面，在“连接与扫描”中选择串口，波特率先选 `1000000`，点击“连接”。
3. 点击“Ping”确认 ID 1 是否在线。若失败，依次尝试 115200、500000、250000、57600、38400，或使用“自动探测 ID1”。
4. 点开“实时反馈”，点击“读取一次/开始轮询”，观察位置、速度、电压、温度、电流。
5. 点开“位置控制”，先“打开扭矩”，确认机械安全后写目标位置。
   初次测试建议：
   - 目标位置：`2048`（约 180°）或接近当前位置；
   - 速度：`60`（约 43.9 RPM）；
   - 加速度：`10~30`；
   - 目标电流：从 `200`（约 1.3 A）左右开始，根据负载调整。
6. 修改 ID、波特率、角度限制等 EPROM 参数前，建议先关闭扭矩，必要时关闭写入锁。
   修改 ID 后需要重新连接/扫描新 ID；修改波特率后需要重新连接新波特率。
7. 整机装配时，用“舵机初始化”页签给 15 台新舵机编号并做初始位置校准，见下一节。

## 整机 15 台舵机初始化

microduck 有 15 个关节，新舵机出厂都是 **ID 1 / 1 Mbps**，需要逐个改成对应的关节 ID。
“舵机初始化”页签把这套流程做成了向导：**一次接一个新舵机**，改完一颗拔下来换下一颗。

### 关节表（来自机器人软件，不是本工具自造的）

关节角零点在 **2048 计数**上、**方向 = −1**，与 `microduck_feetech` 的驱动层一致
（`duck-control/src/feetech.rs` 的 `POSITION_CENTER` / `POSITION_DIRECTION`）：

```text
关节角 = DIRECTION · (计数 − 2048) · 2π/4096        DIRECTION = −1（实测）
计数   = 2048 + DIRECTION · 关节角/0.0879°          都在 0..4095 内
```

位置字段是干净的 **0..4095**、没有负值、没有方向位。**方向是实测值，不是继承值**：
XL330 那一代是 `+1`，HD-1910-C001 在同样的舵盘安装下转向相反（2026-10-03 手转三个关节，
`microduck_feetech/docs/robot/joint-direction-check.md`）。所以下表给两个数：

- **关节角计数** = `DEFAULT_POSITION` 换算出来的角度（可负，left_hip_pitch = −299）；
- **舵机字段** = 要写进 42/56 号寄存器的值 = `2048 + 方向 × 关节角计数`
  （方向 −1 时 left_hip_pitch = **2347**，负角在字段里表现为 2048 **以上**的计数）。

> **2026-10-05 更正。** 本页与工具在 2026-10-03 方向翻转之前写的是 `rad = +(计数 − 2048)·…`、
> 「舵机字段 = 2048 + 关节角计数」，那一列**整列是镜像的**（left_hip_pitch 曾写 1749）。
> 照旧表把关节摆过去，15 个关节会全部对到镜像位置；`POSITION_DIRECTION` 现在是唯一的
> 符号来源，`hls_debugger/selftest.py` 有一条用例直接读 `feetech.rs` 核对它。

| 部位 | 关节名 | ID | home 姿态 | 关节角计数 | 舵机字段（2048 − 角） |
|---|---|---|---|---|---|
| 左腿 | left_hip_yaw | 20 | 0.000° | 0 | **2048** |
| 左腿 | left_hip_roll | 21 | −5.002° | −57 | **2105** |
| 左腿 | left_hip_pitch | 22 | −26.236° | −299 | **2347** |
| 左腿 | left_knee | 23 | −0.281° | −3 | **2051** |
| 左腿 | left_ankle | 24 | 25.955° | 295 | **1753** |
| 头颈 | neck_pitch | 30 | 20.002° | 228 | **1820** |
| 头颈 | head_pitch | 31 | 20.002° | 228 | **1820** |
| 头颈 | head_yaw | 32 | 0.000° | 0 | **2048** |
| 头颈 | head_roll | 33 | 0.000° | 0 | **2048** |
| 头颈 | mouth | 34 | 0.000° | 0 | **2048** |
| 右腿 | right_hip_yaw | 10 | 0.000° | 0 | **2048** |
| 右腿 | right_hip_roll | 11 | 5.002° | 57 | **1991** |
| 右腿 | right_hip_pitch | 12 | 26.236° | 299 | **1749** |
| 右腿 | right_knee | 13 | 0.281° | 3 | **2045** |
| 右腿 | right_ankle | 14 | −25.955° | −295 | **2343** |

> 2048 是**关节角 0**，不是 home 姿态。两者相差上表两列之差：例如 left_hip_pitch 站在 home
> 姿态时读数应该是 **2347**，而"关节角 0"读 2048。整机装舵盘时别把这两个混起来。

这张表抄自 `microduck_feetech`（官方 microduck 的飞特舵机适配版）：

- `duck-control/src/model.rs`：`JOINT_IDS`（15 个总线 ID）、`DEFAULT_POSITION`（home 姿态角）、
  `FACTORY_ID = 1`、`EXPECTED_BAUD_CODE = 0`、`IMU_DXL_ID = 200`；
- `duck-ipc-proto/src/lib.rs`：`JOINT_NAMES`（关节名，顺序与 ID 表一一对应）。

`model.rs` 里那几条常量顺带钉死了本工具依赖的两个前提：**ID 1 与 200 都不属于任何关节**，
所以“总线上出现 ID 1”就等于“有一颗还没编号的新舵机”；新舵机出厂就在 1 Mbps，
不需要换波特率去找它。`selftest.py` 里有一条用例把这张表与 model.rs 的期望值逐项对齐，
改动机器人软件时它会先失败，而不是让工具悄悄用错表。

### 初始化一台舵机做了什么

1. **预检**：ID 1 必须在线；目标 ID 必须没有应答（已在线的关节会被拒绝，避免重复 ID）；
   顺便报告总线上还有哪些关节、有没有 IMU 节点。
2. **关闭扭矩**（40 号 = 0），厂商的 `unLockEprom()` 也是这个顺序。
3. **关闭写入锁**（55 号写 0，EPROM 写入掉电保存）→ **写主 ID**（5 号）→ 写完后
   舵机就开始用新 ID 应答，所以上锁也要发给新 ID。
4. **写波特率**（6 号 = 0，1 Mbps）与**应答状态级别**（8 号 = 1，保证后续指令都有应答）。
5. **9/11 号角度限制**：勾选「打开多圈绝对位置控制」写 **0/0**（多圈，取消固件行程限制），
   不勾选写 **0/4095**（单圈行程）。这个开关**两个方向都会真的写寄存器**——
   「关闭」是把 0/4095 写回去，不是跳过不写，所以对一台已经开过多圈的舵机同样有效。
   **界面默认关闭**（台面单机调试一圈内更安全）；整机装配必须打开，见下面《真机实测》。
6. **19 号卸载条件**（EPROM 位域，见 `memory_table.PROTECT_BITS`）：BIT0 电压保护、
   BIT1 磁编码、BIT2 过热、BIT3 过流保护，置 1 表示**触发时舵机卸载**（不再输出扭矩）。
   界面上有两个选项（电压 / 过流），**默认都不打开**——关节中途卸力就是摔倒，
   这个取舍交给人来定。工具按**读改写**只动 BIT0/BIT3，BIT1/BIT2 保持舵机原值。
7. **写位置环增益**：EEPROM **21/22**（掉电保存，上电加载进 RAM）与 RAM **50/51**
   （立即生效）。默认 **Kp = 32、Kd = 0**，两个都能在界面上改。
   **不要用 `robotd` 那份默认的 200**：那是给 XL330 的 0..16383 标度调的，在飞特
   0..254 上是顶格，实测会让关节自激振荡（5 A、74 °C）。`Kd` 写 0 是为了与
   `duck-control` 的 `set_gain` 对齐——robotd 接管后会用 `robotd.toml` 的 `gain`
   覆盖 RAM 50，所以**两边要一致**，见下面《真机实测》。
8. **初始位置校准**（按下面选的方式）。
9. **打开写入锁**（55 号写 1，EPROM 掉电不保存），再回读 ID / 波特率 / 锁 / 模式 /
   角度限制（按上面的选择校验单圈 0/4095 或多圈 0/0）/ **19 号卸载条件** /
   位置偏移 / 15 字节反馈做校验。
10. 结束时关闭扭矩，并提示断电、拔下、换下一颗。

写入锁的措辞容易记反，按厂商内存表的字面意思：**写 0 = 关闭写入锁**（能改 ID/波特率，
掉电保存），**写 1 = 打开写入锁**（掉电不保存）。所以“解锁”是写 0，“上锁”是写 1。

#### 还有一条：56 号位置读数必须在单圈 0..4095 里（2026-10-05 加）

出厂 **18 号相位 = 0x34**（bit 4「角度反馈模式 = 全角度」，15 个舵机完全一致，真机实测）
时，位置读数**不会自己回绕**：关节被手推过一整圈之后 56 号会读到 4096 以上。`robotd`
的驱动层只读单圈字段（`bus.rs` 的注释写着 "masks around rather than solves"），超出的
读数被取模屏蔽——于是"目标 == 实测"看着一切正常，其实差着一整圈，**下一次写目标就把
关节转回去一整圈**。2026-10-05 真机：`head_yaw` 读到 **6289**，`robotctl robot init`
时脖子飞快转了两圈，并且把相邻的 `head_roll` 顶进了过流错误（status `0x08`），
连 `robotctl robot relax` 都写不进去（"cannot cut torque"）。

初始化流程现在会**检查并修复**这一条：按**整圈挪 31 号位置偏移**把读数搬回窗口。
关节角是 `方向 · ((位置 mod 4096) − 2048)`，整圈平移对它不变，所以**物理姿态一动不动**；
只有整圈平移会超出偏移量程（±4095）时才失败，让人先把关节转回来。
**工具不在这里动相位**：全角度反馈是这批舵机的出厂约定，改它等于改整机的反馈表示；
真正需要改的是"读数跑出单圈之后没人管"这件事。

### 15 台列表的读法（点检 15 台 / 检测总线）

列表按 **ID 升序**排列（`10~14 / 20~24 / 30~34`），点一次 **点检 15 台** 或 **检测总线**
就逐个 PING 全部 15 个关节，把结果画成三种状态：

| 显示 | 含义 |
|---|---|
| 黄色（●） | 该 ID 在总线上**有应答**（来自 `census` / `precheck` 的 `present_joints`） |
| 绿色（✔） | **本页向导已经完成**过这个关节的初始化/校准（进度标记） |
| 灰色（序号） | 还没点检过，或无应答 |

列表与「下一个关节」的推进顺序都是 ID 升序；接口 `/api/joints` 本身仍按
`model.rs` 的 `JOINT_IDS` 顺序（左腿→头颈→右腿）返回，界面只改显示顺序。

点检结果表会同时列出每个在线舵机的**多圈状态**与 **19 号卸载条件**（含打开的保护位名），
方便装配前一眼看出哪台舵机的零位/保护配置与预期不同。点检是**完整点名**：
本次没有应答的关节会被清成灰色，不会留下上一次的黄点。

### 04 页「中位校准（CAL）」的保存选项

CAL 把**此刻的物理位置**写成单圈中点 **2048 计数（180°）**，并改写 **31 号位置偏移**
（EPROM 字段）。写入锁打开（55 号 = 1）时 EPROM 写入**掉电不保存**，所以厂商的
`CalibrationOfs()` 必须先解锁（55 号 = 0）再 CAL——这一步是必要的，不是可选项。

区别只在于 CAL 之后要不要补一次上锁，界面上就是那个默认勾选的
**「保存到 EPROM 并重新上锁」**：

| 勾选 | 实际动作 | 什么时候用 |
|---|---|---|
| **勾选（默认）** | 解锁 → CAL → **55 号写回 1** | 常规：校准结果已经写完并保存，上锁只是恢复到“EPROM 掉电不保存”的保护状态，不留一颗没上锁的舵机 |
| 取消勾选 | 解锁 → CAL（**保持解锁**） | 连续做多次 CAL / 偏移调试时，省掉每次重新解锁 |

两种情况下**校准结果本身都已经掉电保存**（因为 CAL 是在解锁状态下写的）；
上锁发生在写完之后，不会撤销这次校准。

### 位置环增益：为什么初始化要写它（真机实测）

`robotd` 启动时会按 `robotd.toml` 的 `gain` 把 **RAM 50（Kp）** 覆盖成它自己的值
（`duck-control/src/bus.rs` 的 `set_gain`），而那份配置的默认值 `gain = 200` 是给
Dynamixel XL330 的 **0..16383** 标度调的——在飞特的 **0..254** 上就是顶格。

| RAM 50（Kp） | left_hip_yaw（ID 20）实测 |
|---|---|
| 200 | 自激振荡：峰值电流 4966–5388 mA、目标不动时自报速度 4.37 rad/s、壳温升到 **74 °C** 且持续上升、人耳听到剧烈抖动 |
| **32**（厂商默认） | 峰值 110 mA、平均 20 mA、速度峰值 0.307 rad/s、通电 6 s 温度不变（48→49 °C） |

同一只鸭子、同一份固件、只改这一个数值；其余 14 台在两种增益下电流都接近 0。
所以初始化默认写 32/0，并且**两处都写**（EEPROM 让舵机自己上电时是对的，
RAM 让它不必等下一次上电）。注意这只是台面结论：真正的稳定裕度要按关节在负载下整定。

### 四种初始位置校准方式

| 方式 | 做什么 | 用在哪 |
|---|---|---|
| 中位校准（CAL） | 执行厂商 `CAL(0x0B)`，把**此刻的物理位置**写成 **2048 计数** = 关节角 0，并改写 31 号位置偏移 | 想让所有舵机有一个统一的机械基准时；语义确定、实测可复现。15 台现在就是这个状态 |
| 按 home 姿态写位置偏移 | 把 31 号位置偏移改成「此刻读数 = 该关节 home 姿态角」，目标计数 = **2048 + 方向 × home 角计数**（left_hip_pitch → **2347**） | 整机对齐 `DEFAULT_POSITION`；工具按**正反两种约定**各有界搜索候选偏移、逐个回读验证（见上文实测 3），全不中就把原偏移写回并报失败 |
| 转到中位（2048） | 写目标位置 **2048**（关节角 0、一圈中点），到位后保持扭矩，便于按舵盘标记装配（不写 EPROM） | 推荐：装舵盘时把机械零位定好，31 号偏移保持 0。注意不是写 0——0 是一圈的另一端（≈ −180°） |
| 不校准，只改 ID | 只写 ID/波特率，零位由机械装配决定 | 装好之后再整体校准 |

“重新初始化”模式（界面上可切换）把源 ID 从出厂 ID 1 改成目标 ID 本身，
用于重新编号或**重新校准一颗已经编过号的舵机**；这个模式下不会改写主 ID。

### 真机实测（三条结论，按重要性排列）

在 HD-1910-C001（固件 3.46）上实测。

**1. 出厂设置下负的目标位置不生效——但整机现在不需要负值。**

| 9 号 / 11 号角度限制 | 写目标 −500 | 42 号（目标）回读 | 56 号（当前） | 67 号（目标回读） |
|---|---|---|---|---|
| 0 / **4095**（出厂） | 被接受 | `−500` (0x81F4) | **`0`，舵机没动** | **`0`** |
| 0 / **0**（多圈） | 被接受 | `−500` (0x81F4) | **`−500`** | **`−500`** |

协议层一直「接受」负值（42 号回读就是 −500），但 11 号 = 4095 把位置坐标夹在一圈
`[0, 4095]` 内，负目标被夹到 0。厂商内存表在 9/11 号上写的「多圈绝对位置控制时此值为 0」
就是开关，实测有效。

> **2026-10-05：这条对整机的结论已经反过来，别照旧读。** 关节表里有 4 个 home 姿态角是负的，
> 但工具写下去的**从来不是负值**：单圈 + 「零点 2048、方向 −1」这套坐标把负角表示成 2048
> **以上**的计数（left_hip_pitch −299 → 2347），所以单圈就够了，**不需要**为这 4 个关节
> 打开多圈。现在整机按单圈跑（`robotd` 的审计也要求 9/11 = 0/4095），界面上的开关默认关闭
> 就是整机配置；打开它只在台面上要转到一圈以外、或要写有符号绝对值时才用。

**2. 推荐配置：多圈打开 + 位置偏移保持 0，零位由机械装配决定。**

打开多圈、31 号偏移为 0 时坐标是干净的，负目标精确跟随：

| 写目标 | 当前位置 | 67 号目标回读 |
|---|---|---|
| 0 | 0 | 0 |
| −500 | **−500** | **−500** |
| −1000 | **−999** | **−1000** |
| −300 | **−301** | **−300** |

也就是说：把舵盘装在 home 姿态、让 home 姿态的读数落在目标附近，然后把 31 号偏移
留给「小幅修正」——这条路径实测最稳。代价是固件不再限制行程，行程要靠 `robotd` 兜住。

**3. 拿大偏移去搬原点：那条"重锚"其实可以复算成取模回绕。**

写一个较大的偏移会让固件把编码器坐标**重锚**：实测偏移 −3591→−3091（+500）后读数从
−4096 变成 −500（差 3596），而 −3591→−4591（−1000）后读数从 −4096 变成 −3096（差 1000）
——同一根轴，写偏移前后的差值不是同一个常量；读数还总被折进约 ±2 圈的窗口。
手册没写这些（`docs/飞特通讯协议说明.md` 第 12.5 节把它列为未确认项）。

> **2026-10-05 复算：那四个点其实都满足 `位置 + 偏移 = −7687`（常数）**，也就是
> `位置 = 编码器 − 偏移` 的线性关系成立，"差值不是常量"是因为读数被折进窗口后再读出来的
> 是**回绕值**（−4596 读成 −500 之类）。所以严格说不是"重锚"，而是"显示窗口取模"。
> 这条目前只是**事后复算**，还没有按公式在真机上写过；等实测确认后再把下面的有界搜索
> 换成一次公式写入。在那之前维持原样。

所以「按 home 姿态写位置偏移」这个校准**不做公式假设**：有界搜索候选偏移（正反两种约定
都试）、逐个回读验证，只有落进 8 计数（≈0.70°）容差才算成功；全都不中就把原偏移**写回去**
并报失败。经验规律是**所需偏移越小越可靠**，所以校准前让读数落在 0 附近最省事
（舵盘换个齿位即可）。

另外两条实测结论：

- **CAL 的「中点」是 2048 计数（180°），不是 0**：CAL 前 偏移 = 0、位置 = 72；
  CAL 后 偏移 = −1976、位置 = 2048。
- 一圈内模式下位置被夹在一圈内，负结果回绕成 `4096 + 值`
  （偏移扫一圈时 −98 → 3999、−498 → 3599、−1998 → 2099）。
- **19 号「卸载条件」出厂只开过热保护**：2026-10-03 在 16 台 HD-1910-C001
  （固件 3.46）上逐台回读，`19 = 4 (0x04)`，即 BIT2 过热保护打开、BIT0 电压、
  BIT1 磁编码、BIT3 过流都**没有**打开。工具的「只按读改写动 BIT0/BIT3」就是按这个
  事实设计的：勾选/取消电压或过流时，BIT1/BIT2 保持原值（真机验证：`4 → 13 → 4`，
  BIT2 全程为 1）。

对 `microduck` 的影响：`duck-control/src/feetech.rs` 的 `position_rad()` 按「BIT15 为方向位」
解读位置字段，与 `DEFAULT_POSITION` 的负角一致；打开多圈后舵机给的正是这种写法。
仍然建议上整机前以 `robotd` 侧读到的关节角复测一次。

校准只改坐标原点，不校验机械姿态：勾选「已把该关节摆到基准位」只是确认你摆好了。
想恢复出厂零位，把 31 号位置偏移写回 0；想恢复一圈行程，把 11 号写回 4095。

### 界面之外：对应 API

| 用途 | 接口 |
|---|---|
| 关节表与校准方式 | `GET /api/joints` |
| 上电预检（该在的在、不该在的别在） | `POST /api/provision/precheck` |
| 初始化一颗（写 ID/波特率/多圈/**位置环增益**/校准/上锁/回读） | `POST /api/provision` |
| 点检 15 台谁在线 | `POST /api/provision/census` |

`POST /api/provision` 的参数：`id`（目标关节 ID）、`mode`（`fresh` / `reinit`）、
`calibrate`（`cal` / `offset` / `mid` / `none`）、`multiturn`（**默认 `false`**；
`true` 把 9/11 号写成 0/0，`false` 写回 0/4095 单圈行程）、
`protect_voltage` / `protect_over_current`（19 号 BIT0/BIT3，**默认都 `false`**）、
`write_response_level`、`write_gain`、`gain_kp` / `gain_kd`、`speed`、`acc`。
返回逐步的 `steps` 明细、`calibration` 实测值、`multiturn` / `protect` 回显和
`snapshot` 回读结果（`snapshot` 里含 `unload_condition` 与 `protect_voltage` /
`protect_over_current`）。

`POST /api/calibrate` 的参数：`id`，以及 `save`（**默认 `true`**）——
`true` 时解锁 → CAL → 补写 55 号 = 1，`false` 时保持解锁；返回里的 `saved`
与 `lock`（上锁应答帧或 `null`）说明实际做了什么。

### 安全须知

- **一次只接一个新舵机**：两颗出厂 ID 都是 1 的舵机同时在线时会被一起改名，
  产生重复 ID，之后整条总线的读写都会互相打架。
- 初始化会写 EPROM，并且 CAL / 转到位置 0 会让舵机转动，请先确认机械安全、可以随时断电。
- 用 CAL 或位置偏移校准前，先确认这颗舵机确实处在它该在的基准位。
- **电压 / 过流保护（19 号）默认不打开**：它们触发时舵机会卸载（不再输出扭矩），
  对一条腿站着的机器人等于摔倒。要在整机上打开就明确知道自己在换什么。
- 想恢复出厂零位，把 31 号位置偏移写回 0 并重新上电即可。

## 内存表关键换算

| 字段 | 换算 |
|---|---|
| 位置 42/56/67 | 1 计数 = 0.087°，4096 计数/圈；手册称 BIT15 方向，实测本机负值写法不稳定（见上文实测） |
| 速度 46/58 | 1 计数 = 0.732 RPM，BIT15 方向 |
| 负载 60 | 1 计数 = 0.1% 占空比，BIT10 方向 |
| 电压 62 | 1 计数 = 0.1 V |
| 电流 44/69 | 1 计数 = 6.5 mA，BIT15 方向 |
| 加速度 41 | 1 计数 = 8.7 °/s²，0 = 最大 |
| 转矩 16/48 | 1 计数 = 0.1% |
| Kp/Kd 50/51 | 位置模式 Kp 刻度 1/8，Kd 刻度 1/4 |
| 位置偏移 31 | 1 计数 = 0.087°；实测 `位置 ≡ 编码器 − 偏移 (mod 4096)` |

特别提醒：HLS 位置是 **4096 计数/圈**，不是 32768 计数/圈。
早期资料若按 32768 计算会有 8 倍误差。

## 与参考库的对应关系

| 参考库方法 | 工具入口 | HTTP API |
|---|---|---|
| `Ping(ID)` | Ping / 扫描 | `POST /api/ping` |
| `Read/readByte/readWord` | 通用读、参数配置、实时反馈 | `POST /api/read` |
| `genWrite/writeByte/writeWord` | 通用写、参数配置 | `POST /api/write`、`POST /api/write_field` |
| `regWrite` | 异步写 | `POST /api/reg_write` |
| `RegWriteAction` | 执行异步写 | `POST /api/reg_action` |
| `WritePosEx` | 位置控制 | `POST /api/move` |
| `RegWritePosEx` | 异步写位置 | `POST /api/move` (`reg=true`) |
| `SyncWritePosEx` | 同步位置写 | `POST /api/sync_move` |
| `SyncWriteSpe` | 同步速度写 | `POST /api/sync_wheel` |
| `ServoMode/WheelMode/EleMode` | 模式按钮 | `POST /api/mode` |
| `WriteSpe` | 恒速模式 | `POST /api/wheel` |
| `WriteEle` | 恒流模式 | `POST /api/electric` |
| `EnableTorque` | 扭矩开关 | `POST /api/torque` |
| `unLockEprom/LockEprom` | 写锁控制 | `POST /api/lock` |
| `CalibrationOfs` | 中位校准 | `POST /api/calibrate` |
| `FeedBack` | 实时反馈 | `POST /api/feedback` |
| `Reset` | RESET | `POST /api/reset` |
| `Recal` | CAL | `POST /api/calibrate` |
| 原始协议 | 原始帧收发 | `POST /api/raw` |
| 整机初始化 | 舵机初始化页签 | `GET /api/joints`、`POST /api/provision/precheck`、`POST /api/provision`、`POST /api/provision/census` |

## 故障排查

- **爆出“打开串口失败”**：检查设备名、USB 线、供电、`dialout` 权限。
- **一直等待应答超时**：优先检查波特率是否匹配；HLS 默认 1 Mbps。
- **Ping 收到但读写失败**：确认 ID 是否为总线地址/副 ID；确认目标设备不是只响应主 ID。
- **写 EPROM 不保存**：写 55 号锁标志为 0（关闭写入锁）后再写，然后重新上电验证。
- **修改 ID/波特率后连不上**：换用新 ID/新波特率重新连接。
- **同步写没反应**：SYNC_WRITE 是广播，没有应答；先确认舵机处于正确模式，且每个 ID 的数据长度一致。
- **位置角度不对**：按 4096 计数/圈换算，且**零点在 2048、方向是 −1**
  （`关节角 = −(计数 − 2048) · 0.0879°`）。扭矩关掉后位置可能可以手动转动，这是正常现象。
- **负角关节不进反方向 / 写负位置舵机不动**：出厂 11 号最大角度限制 = 4095 把行程
  锁在一圈内，**负数**目标会被夹到 0。整机现在不需要负值——单圈 + 「零点 2048、方向 −1」
  把负的关节角表示成 2048 以上的计数（left_hip_pitch −299 → 2347），所以保持单圈即可。
  只有台面上要转到一圈以外时才用「舵机初始化」页签勾上「打开多圈绝对位置控制」，
  或手动把 9 号与 11 号都写 0。实测对照见上文《真机实测》。
- **位置偏移校准报「没能把读数调到…已把位置偏移恢复为…」**：说明当前读数离目标
  太远。把关节摆到更接近 home 的位置，或把舵盘换个齿位让读数落在目标附近再校准；
  工具已经把偏移恢复成原值，不会留半校准状态。
- **初始化说“ID 1 没有应答”**：确认只接了新舵机、已上电、波特率是 1 Mbps；
  用“连接与扫描”里的“自动探测 ID1”或全总线扫描确认它到底在不在。
- **初始化说“目标 ID 已经在应答”**：这个关节已经编过号了。要么换一颗新舵机，
  要么把界面上的模式切到“重新初始化”。
- **初始化说“目标 ID 是 20 却报 ID 是别的”**：多半是总线上有重复 ID，
  或者目标 ID 的舵机不是你以为的那一颗。先用“点检 15 台”看清楚谁在线。
- **CAL 之后读数是 2048**：这是正确的——**2048 就是关节角 0**，与 robotd 的驱动层一致，
  不是旧文档里说的“180° 中点所以不对”。想看 home 姿态该读多少，用上表的「舵机字段」列
  （left_hip_pitch 是 **2347**）。
- **负角关节的偏移校准目标是多少**：`2048 + 方向 × home 角计数`。`left_hip_pitch` 的 home 角
  是 −299 计数、方向 −1，所以目标是 **2347**（不是 −299，也不是 1749——1749 是**镜像**位置）。
  界面上会直接把目标数打出来。
- **我照着一张写着 1749 的表把关节摆过去了**：那张表是 2026-10-03 方向翻转之前的，
  整列镜像。正确值见上表；摆错的后果是 15 个关节全部对到镜像位置（`robotctl monitor`
  会显示每个关节读 π 附近或明显反向）。
- **明明取消了多圈、9/11 号却还是 0/0**：这是旧版的行为（取消勾选只是“跳过不写”）。
  现在两个方向都会真的写寄存器，取消勾选就把 9/11 号写成 0/4095；如果回读仍不是，
  看结果框里的「关闭多圈，恢复单圈行程」那一步回读值是多少。
- **点检后黄点/绿点不对**：黄点来自最近一次「点检 15 台」或「检测总线」的完整点名，
  绿点是**本页**的完成标记（刷新页面会清掉），两者都不代表舵机的零点真的校好了。
- **扫描少发现舵机（已修）**：早期扫描范围默认只到 ID 20，把 ID>20 的舵机整段漏掉
  （实测 10~14、20、21 共七台只报 6 台，漏的正是 21）。现已把界面、`/api/scan`、
  `HLSBus.scan()` 的默认上限全部改为 **253**，默认全总线扫描约 12 秒。
  注意扫描区间是**闭区间**：结束 ID 必须 ≥ 最大舵机 ID。
- **写运行模式 4 被拒绝（已修）**：`HLSBus.set_mode()` 原先按手册的 `0~3` 校验，
  但本机型出厂就是模式 4（与模式 0 同属位置环），界面上的“位置 (4)”按钮因此会报错。
  现已放开到 `0~4`。

## 安全提示

调试软件可以通过浏览器直接驱动舵机。所有写入都会立即发送到总线，
请务必：
- 固定好机械结构，避免堵转、飞车或夹伤；
- 初次使用低速度、低加速度、低电流；
- 随时准备断开舵机电源；
- **注意：写目标位置会自动打开扭矩**（实测本固件行为），所以"关闭扭矩"后
  再写位置会重新带电；需要卸力时请在最后一次位置写入之后再点"关闭扭矩"。
  这一条对机器人软件同样成立，而且是 `robotctl robot relax` 曾经"卸不了力"的原因：
  控制环每个 tick 都会写目标位置，于是卸力只维持了不到 20 ms。修法见
  `microduck_feetech/FORK.md` 的「`robot relax` 卸不了力」一节与
  `duck-control/src/safety.rs` 的 `Safety::powered`；
- 不要把 `RESET`、`CAL`、改 ID/波特率等操作当成常规测试按钮反复点击；
- 整机初始化会写 EPROM，而且 CAL / 转到位置 0 会让舵机动起来；
  **一次只接一个新舵机**，否则两颗出厂 ID 1 的舵机会被一起改名，产生重复 ID；
- 重复 ID 会让总线上所有读写互相打架，且症状像接线故障，接线时务必一颗一颗来。

## 无硬件自检

不连接舵机也可以运行协议自检，验证帧构造、校验和、串口读取状态机、
同步读解析、内存表编解码、反馈解码，以及用一个从站模拟跑完整套
“出厂 ID 1 → 关节 ID + 校准”的初始化流程：

```bash
uv python -m hls_debugger.selftest
```

## 真机连通性测试

`hw_test.py` 用真实串口完成只读验证（只发 PING 和 READ，不发任何运动指令）：

```bash
uv python hw_test.py --port /dev/ttyACM1
```

它会打印设备信息、各波特率下的 ID 扫描、版本/ID/波特率/模式/扭矩/写锁，
以及 56~70 号 15 字节实时反馈的完整解码。若首个波特率无应答，会自动遍历
`1000000 / 115200 / 500000 / 250000 / 128000 / 76800 / 57600 / 38400`。

### 现场注意

- 波特率索引 0 = 1 Mbps，与本工具默认一致；改波特率后需按新速率重连。
- 锁标志为 1 时写 EPROM 掉电不保存，**改 ID/波特率等需先解写锁（55 号写 0）**。
- 位置偏移会把读数整体平移，且按一圈取模；负值有时报负、有时回绕，属实测现象。
  校准请用“舵机初始化”页签，它按一圈取模比较、留容差并回读校验。

## 实机操作记录（供复现参考）

以下步骤在本工具上对真机跑通过，可作为复现脚本的参照：

1. 接上出厂新舵机到 `/dev/ttyACM0`，连接后 `POST /api/provision/precheck {"id":20,"mode":"fresh"}`：
   `source_present=true`、`target_present=false`。
2. `POST /api/provision {"id":20,"mode":"fresh","calibrate":"cal"}`：
   ID 1 → 20，波特率 0，应答级别 1，CAL 把位置 72 写到 2048，上锁，状态 0。
3. `POST /api/provision {"id":20,"mode":"reinit","calibrate":"mid","speed":80,"acc":20}`：
   输出轴从 2048 转到 0（误差 2 计数 ≈ 0.18°），扭矩保持开启。
4. `POST /api/provision {"id":20,"mode":"reinit","calibrate":"offset"}`：
   位置偏移 3000 → 2121，读数 3217 → 0，校验通过。
5. `POST /api/provision/census`：应报出全部已编号的关节，未编号的位置显示“—”。

### 2026-10-03：本轮改动的真机验证（`/dev/ttyACM0`，16 台在线）

总线上是 16 台 HD-1910-C001（固件 3.46 / 舵机 10.31）：ID `1, 10~14, 20~24, 30~34`，
1 Mbps。测试**全部可逆**，结束前逐项写回，收尾用同一份只读盘点与测试前逐字节比对。

| 验证项 | 结果 |
|---|---|
| 9/11 号两个方向（`_set_multiturn`） | `0/4095 → 0/0 → 0/4095` 全部回读一致（ID 1） |
| 19 号读改写 | `4 (0x04) → 13 (0x0D) → 4 (0x04)`，BIT2 过热全程保持为 1（ID 1） |
| 55 号解锁/上锁 | 解锁回读 0、上锁回读 1（ID 1） |
| CAL 保存（`save=True`） | 解锁 → CAL（位置 1 → 2048、偏移 0 → −2047）→ 补写 55 = 1；随后把偏移写回 0，读数恢复 1 |
| 整流程 `provision(mode=reinit)` | 对在线关节 ID 20 跑完 14 个步骤全部 OK，含“关闭多圈，恢复单圈行程”与
“写卸载条件（19 号）”两步和最终回读校验（单圈行程 + 卸载条件都在校验项里） |
| 收尾比对 | 16 台的 9/11、19、31、相位、模式、扭矩、锁、增益、ID 与测试前完全一致 |

过程中的两点观察：本轮之前 15 台关节的 9/11 **都是 `0/0`（多圈）**、31 号偏移都是 0，
19 号都是 `4`；而 ID 10 是唯一被手工改过的（`9/11 = 0/4095`、`19 = 13`、偏移 −595、
锁 0），说明这些寄存器确实被独立写过、回读可信。另外 `snapshot()` 现在多读一个 19 号，
点检 15 台会因此多 15 次单字节读——实测 15 台总耗时仍在 1~3 秒量级。

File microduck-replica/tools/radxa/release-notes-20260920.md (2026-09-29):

> **2026-09-28 联网勘误，请先读：** 旧版制卡脚本遗漏了 `wlan0` 的 DHCP 配置。即使 WiFi 名和密码正确，也可能无法取得 IPv4 地址，导致 SSH 找不到主板。仓库脚本已经补上；已经烧录的卡可按下文补配置，不必仅为此重刷。
>
> **本 Release 的 `.img.xz` 镜像和 `sha256.txt` 仍为 9 月 20 日的原文件，没有包含本次修复。** 本次更新的是 Release 说明、随附使用指南和仓库制卡脚本。卡内 `/root/先连WiFi.txt` 是旧提示，请以更新后的指南为准。本机修复后的个人镜像已实测取得 DHCP 地址并通过 SSH 登录，`networkctl` 确认使用新增配置；这是单台设备的验证，不等于公开镜像已替换或所有失联问题都已解决。

这是面向此前本机 Radxa Zero 3W V1.12（AIC8800 WiFi）引导兼容性问题制作的社区镜像：使用 Armbian 26.2.1 Trixie vendor 6.1.115 minimal 的内核和系统软件包，替换瑞莎引导程序，并调整启动、登录和网络配置。不同板卡批次需单独验证。

**绿灯双闪可为正常 `heartbeat`，不能单凭闪灯判断启动失败或镜像损坏。** 基础镜像也不等于已安装完整机器人软件；联网、摄像头和舵机控制要分别验收。

### 下载哪个

| 文件 | 说明 |
|---|---|
| `armbian-26.2.1-zero3w-v1.12-bootfix-20260920.img.xz` | 原公开镜像，不含 WiFi 名/密码；烧录后必须配置 WiFi 并补上 DHCP。可用 Rufus / balenaEtcher / Armbian Imager 写卡 |
| `sha256.txt` | 上述原镜像的 SHA256，保持不变 |
| `radxa-zero3w-image-guide-zh.md` | 2026-09-28 更新：首次联网、旧卡修复、换 WiFi、USB 接口与供电说明；内容与[仓库使用说明](https://github.com/fanhao375/microduck-replica/blob/master/tools/radxa/%E9%95%9C%E5%83%8F%E4%BD%BF%E7%94%A8%E8%AF%B4%E6%98%8E.md)同步 |

原 `.img.xz` 文件的 SHA256：

```text
4de8a355d3d9180e465af486c409e9b3e4ac82c0e241dc73d4fc0f0db7a67579
```

### 第一次烧录和登录

1. 校验镜像后烧入至少 8 GB 的卡。
2. 使用**能传数据的 USB 线**，连接主板 **`5V IN / USB_OTG`（USB 2.0）口**和电脑，由 USB 单独供电。另一个 **USB 3.0 Host** 口用于外设，不是电脑连接板载 USB 串口的接口。
3. 首次启动先等约 2~3 分钟；正常启动并加载 USB gadget 后，电脑应出现 COM 口。串口工具设 **115200 8N1**，回车登录 `duck` / `duck1234`（root 初始密码同为 `duck1234`）。运行 `passwd` 和 `sudo passwd root` 修改默认密码。没有 COM 口时先检查接口、数据线和供电，不能只看绿灯。
4. 公开镜像没有预设 WiFi。按[使用说明第 4 节](https://github.com/fanhao375/microduck-replica/blob/master/tools/radxa/%E9%95%9C%E5%83%8F%E4%BD%BF%E7%94%A8%E8%AF%B4%E6%98%8E.md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)的“第一次联网，或者更换 WiFi”配置无线认证和 DHCP；基础镜像没有安装 NetworkManager，不能直接用 `nmtui`。

**HAT 供电提醒：** HAT / 40 针的 5V 与 USB_OTG 的 VBUS 接在同一电源网络，不要同时接 HAT 电源和普通电脑 USB 数据线供电。需要改用 USB 串口时，先正常关机、断开 HAT 输入，再切到 USB 单独供电；HAT 供电调试优先通过 WiFi + SSH。

### 旧卡已经填好 WiFi：只补 DHCP

以下用于仍采用 `wpa_supplicant` + `systemd-networkd` 的本项目基础镜像。如果后续已经迁移到 NetworkManager，请通过它检查连接和 IPv4 自动获取，不要同时启用两套无线管理服务。

通过 USB 串口或本地终端登录，保留原来的 WiFi 名和密码，执行：

```bash
sudo mkdir -p /etc/systemd/network
sudo tee /etc/systemd/network/25-wlan0.network >/dev/null <<'NETWORK'
[Match]
Name=wlan0

[Network]
DHCP=ipv4
NETWORK
sudo chmod 644 /etc/systemd/network/25-wlan0.network
sudo systemctl enable --now systemd-networkd wpa_supplicant@wlan0
sudo networkctl reload
sudo networkctl reconfigure wlan0
```

等待约 30 秒，再检查：

```bash
sudo wpa_cli -i wlan0 status   # 应有 wpa_state=COMPLETED
ip -4 a show wlan0            # 应有路由器分配的 IPv4 地址
ip -4 route                   # 应有默认路由
networkctl status wlan0       # 看匹配的配置及 DHCP 状态
```

默认 netplan 只匹配有线网卡；`wpa_supplicant` 负责无线认证，本次补的 `25-wlan0.network` 让 `systemd-networkd` 为无线接口申请 IPv4 地址。**只填 WiFi 密码不等于已经配好 DHCP。**

若仍不通，按顺序检查：有没有 `wlan0` → 无线认证是否完成 → 是否获得 IPv4 地址和默认路由 → 电脑与主板是否在同一个可互通的局域网。认证未完成先查名称、密码、信号和路由器模式；此补丁不能代替这些检查。详细诊断命令见随附指南。

### 换电脑 / 换 WiFi 要不要重刷

- **换电脑不需要重刷。** 电脑和主板在同一个可互通的局域网，用 `ssh duck@主板IP` 登录即可；访客网络或 AP 隔离可能阻止互访。
- **换 WiFi 需要重新填写新网络的名称和密码，不需要重刷。** 从 USB 串口或本地终端按指南第 4 节重新配置；重启无线服务会断开原来的无线 SSH。
- DHCP 地址可能变化，请通过主板 `ip -4 a show wlan0` 或路由器设备列表重新找 IP，不要固定沿用以前的地址。
- 想烧卡前预设自己的 WiFi，可使用修正后的[制卡脚本和配置说明](https://github.com/fanhao375/microduck-replica/tree/master/tools/radxa)。自己生成的带密码镜像仅供个人使用，不要公开上传。

本镜像的无线凭据不在 netplan 中，**不要直接照搬上游 `migrate-network.sh` → 重启的流程**。先保持当前可用连接，迁移前需适配凭据导入、旧服务退出和失联恢复；否则可能因网络管理服务争抢或未导入密码而失联。

### 引导、外设与板卡批次

原镜像换入 `u-boot-rk2410` 引导，使用 `extlinux.conf` 启动；配置 `uart2-m0` 和 `dwc3-peripheral` overlay，并将登录控制台从舵机串口移到 USB gadget。它们分别用于 `/dev/ttyS2` 舵机串口和 USB 串口登录，不代表机器人控制软件已安装或硬件已验收。

2026-09-28 本机还完成了 HAT 舵机只读通讯测试；已能读到关节状态，但左膝 23 号出现间歇无应答，保护配置和运动验收也未完成。见[联网与 HAT 实测记录](https://github.com/fanhao375/microduck-replica/blob/master/tools/radxa/%E8%81%94%E7%BD%91%E4%B8%8EHAT%E8%B0%83%E8%AF%95%E8%AE%B0%E5%BD%95-20260928.md)。

群友报告在其 V1.12J / AIC8800DS2 板上，通过 **B1 引导 + B1 DTB + Armbian 6.1.115 内核 + Trixie 系统** 跑通；本项目尚未独立验证这一组合。不能仅凭内核同为 6.1 就认定 DTB 通用，换 DTB 后还需检查串口和 USB overlay。相关经验和操作注意事项见指南第 6 节。

2026-09-28 摄像头测试是在**瑞莎官方 B1** 上，调整排线方向/接触后识别 IMX219 并完成 40 帧短测；本项目 Armbian 镜像上的复测尚未完成。见[接线图与调试记录](https://github.com/fanhao375/microduck-replica/blob/master/tools/radxa/%E6%91%84%E5%83%8F%E5%A4%B4%E8%B0%83%E8%AF%95%E8%AE%B0%E5%BD%95-20260928.md)。

### 来源与许可

- 底包：[Armbian 官方 Radxa Zero 3 镜像](https://www.armbian.com/radxa-zero-3/)，26.2.1 Trixie vendor 6.1.115 minimal，GPL 及各软件自身许可。
- 引导：瑞莎 [`u-boot-rk2410`](https://radxa-repo.github.io/bookworm/pool/main/u/u-boot-rk2410/) `2017.09-64-39cd993`，GPL-2.0。
- 制卡步骤见 [`build-armbian-card.sh`](https://github.com/fanhao375/microduck-replica/blob/master/tools/radxa/build-armbian-card.sh)；当前脚本包含 9 月 28 日 DHCP 修复，产物不会与旧 Release 文件逐字节相同。

社区自制镜像，并非 Armbian 或瑞莎官方发布。问题请附板卡版本和已遮去个人信息的日志，在本仓库开 [issue](https://github.com/fanhao375/microduck-replica/issues)。

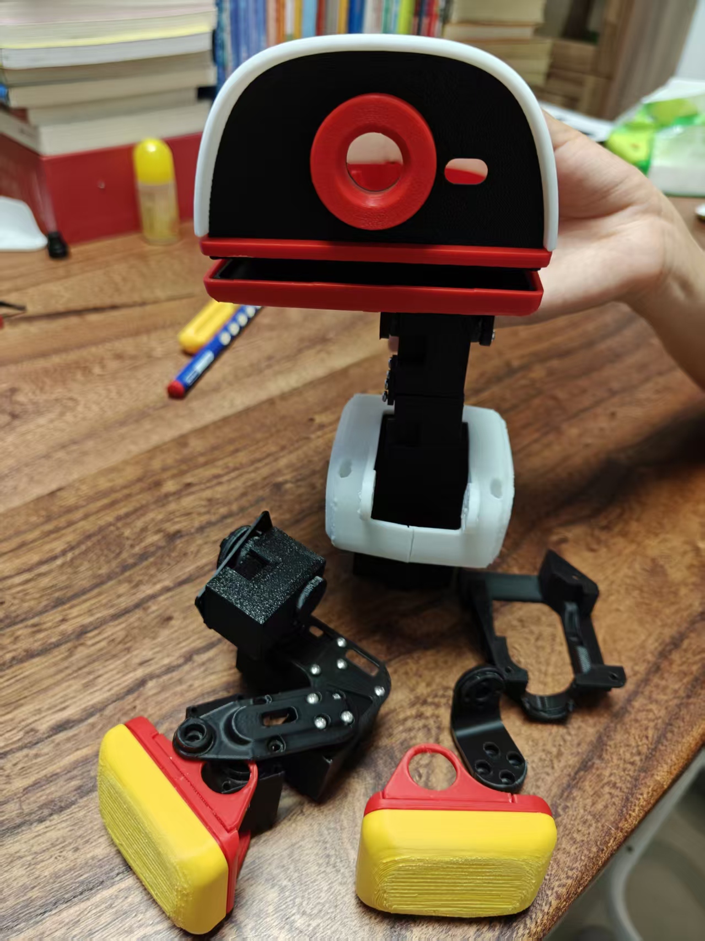
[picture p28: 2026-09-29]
microduck-replica/build-log/photos/2026-09-02-首批打印件.jpg

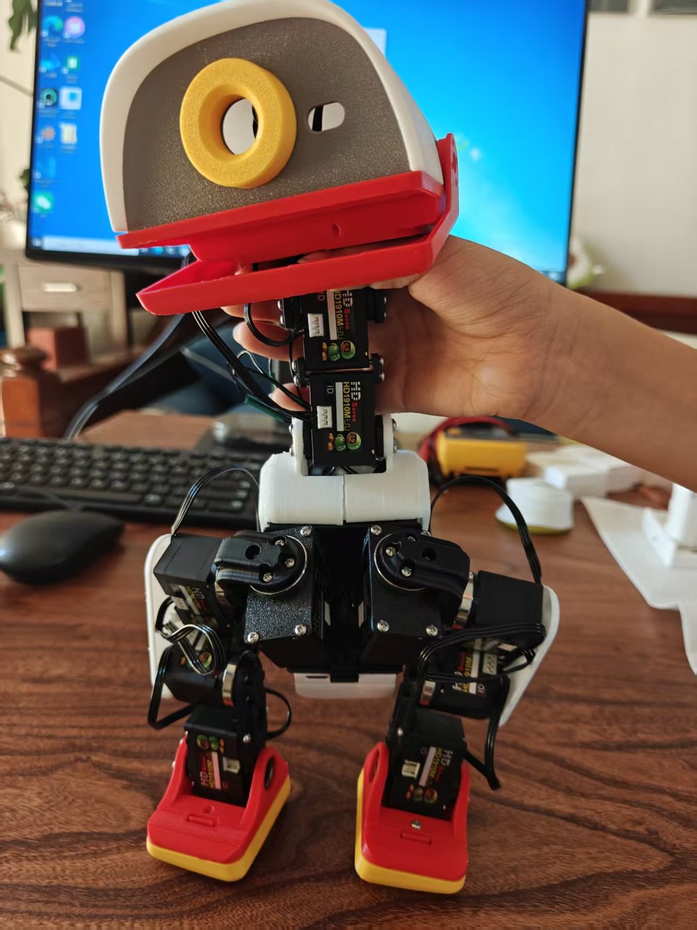
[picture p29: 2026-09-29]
microduck-replica/build-log/photos/2026-09-13-飞特版装机-手持.jpg

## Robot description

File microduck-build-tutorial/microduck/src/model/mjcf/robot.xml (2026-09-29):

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
<mujoco model="microduck">
  <compiler angle="radian" meshdir="assets" autolimits="true"/>
  <default>
    <default class="microduck">
      <joint frictionloss="0.1" armature="0.005"/>
      <position kp="50" dampratio="1"/>
      <default class="visual">
        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
      </default>
      <default class="collision">
        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
      </default>
    </default>
    <default class="xl330">
      <joint damping="0.041" frictionloss="0.013" armature="0.0018"/>
      <motor gear="1"/>
    </default>
  </default>
  <sensor>
    <framequat name="orientation" objtype="site" noise="0.001" objname="imu"/>
    <gyro name="angular-velocity" site="imu" noise="0.005"/>
    <gyro name="imu_ang_vel" site="imu"/>
    <velocimeter name="imu_lin_vel" site="imu"/>
    <accelerometer name="imu_accel" site="imu"/>
    <subtreeangmom name="root_angmom" body="trunk"/>
  </sensor>
  <worldbody>
    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
    <body name="trunk" pos="0 0 0" quat="1 0 0 0" childclass="microduck">
      <freejoint name="trunk_freejoint"/>
      <inertial pos="-0.00454781 -0.000104579 0.053896" mass="0.347283" fullinertia="0.000608722 0.000477224 0.000357224 -5.1387e-07 -1.16287e-05 1.9299e-06"/>
      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
      <body name="head" pos="-0.00204165 -0 0.126" quat="0.707107 0 0 0.707107">
        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
        <joint axis="0 0 1" name="head" type="hinge" range="-1.5707963267949783 1.5707963267948148" class="xl330"/>
        <inertial pos="5.1303e-08 -0.0074561 0.0161837" mass="0.0166215" fullinertia="2.92963e-06 3.58354e-06 4.24694e-06 -1.6e-11 4e-12 2.61187e-07"/>
        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
      </body>
      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
      <body name="shoulder" pos="0 -0.0505 0.081" quat="0.707107 -0.707107 -0 0">
        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
        <joint axis="0 0 1" name="right_shoulder_pitch" type="hinge" range="-3.141592653589793 3.141592653589793" class="xl330"/>
        <inertial pos="4.19e-10 2.814e-09 -0.00850029" mass="0.00898451" fullinertia="1.06003e-06 1.78233e-06 1.86739e-06 0 0 -0"/>
        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
        <body name="humerus__configuration_right" pos="0.0145 0 -0.0195" quat="0 0.707107 0 0.707107">
          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
          <joint axis="0 0 1" name="right_shoulder_roll" type="hinge" range="-3.1415926535897922 8.881784197001252e-16" class="xl330"/>
          <inertial pos="-0.000309872 -0.0252784 -0.0143918" mass="0.0416867" fullinertia="1.76899e-05 3.95132e-06 1.75854e-05 -3.03216e-07 -2.278e-09 -7.8184e-08"/>
          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
          <body name="radius" pos="-0.0145 -0.0515 -0.0145" quat="0.707107 0 0.707107 -0">
            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
            <joint axis="0 0 1" name="right_elbow" type="hinge" range="-2.181661564992912 2.181661564992912" class="xl330"/>
            <inertial pos="-4.0628e-08 -0.0310611 0.0130165" mass="0.0115415" fullinertia="5.26775e-06 1.21602e-06 4.45903e-06 -4e-12 -1.2e-11 1.7157e-07"/>
            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
          </body>
        </body>
      </body>
      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
      <body name="hip" pos="0 -0.036 0" quat="1 -0 -0 0">
        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
        <joint axis="0 0 1" name="right_hip_yaw" type="hinge" range="-4.188790204786353 1.047197551196635" class="xl330"/>
        <inertial pos="0.00421822 1.46909e-07 -0.00948697" mass="0.00884451" fullinertia="9.36719e-07 4.32505e-06 4.03697e-06 -3.3e-11 1.95496e-07 0"/>
        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
        <body name="hip_block__configuration_right" pos="-0.02 0 -0.0214" quat="0.5 -0.5 0.5 -0.5">
          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
          <joint axis="0 0 1" name="right_hip_roll" type="hinge" range="-0.610865238197994 0.6108652381980366" class="xl330"/>
          <inertial pos="-5.75932e-05 0.00982795 0.0271518" mass="0.04763" fullinertia="1.64064e-05 1.33088e-05 7.85889e-06 -9.153e-09 7.8745e-08 6.63067e-07"/>
          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
          <body name="femur__configuration_right" pos="-0.0145 -0 0.0385" quat="0 0.707107 0 -0.707107">
            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
            <joint axis="0 0 1" name="right_hip_pitch" type="hinge" range="-1.5707963267948974 1.5707963267948957" class="xl330"/>
            <inertial pos="-0.0109472 -0.0366847 -0.0147025" mass="0.014726" fullinertia="1.12665e-05 4.38335e-06 8.95932e-06 -1.12592e-06 1.333e-09 -4.521e-09"/>
            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
            <body name="tibia__configuration_right" pos="-0.005 -0.062 -0" quat="1 -0 0 -0">
              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
              <joint axis="0 0 1" name="right_knee" type="hinge" range="-0.7853981633977201 2.356194490192073" class="xl330"/>
              <inertial pos="0.00276278 -0.0196679 -0.0144621" mass="0.0300463" fullinertia="1.53882e-05 5.3311e-06 1.38581e-05 2.25674e-06 7.6682e-08 -1.37001e-07"/>
              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
              <body name="ankle_block__configuration_left" pos="0.008 -0.0612131 -0" quat="0 -0 -0 1">
                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
                <joint axis="0 0 1" name="right_ankle_pitch" type="hinge" range="-1.5707963267948077 0.6108652381981041" class="xl330"/>
                <inertial pos="-0.0110676 -0.00979852 -0.0144015" mass="0.04722" fullinertia="7.83993e-06 1.29837e-05 1.60971e-05 -6.00742e-07 -4.9782e-08 -6.127e-09"/>
                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
                <body name="foot" pos="-0.0385 0 -0.0145" quat="0 -0.707107 0 -0.707107">
                  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
                  <joint axis="0 0 1" name="right_ankle_roll" type="hinge" range="-0.610865238197748 0.6108652381982826" class="xl330"/>
                  <inertial pos="-0 -0.0168869 0.0347422" mass="0.016823" fullinertia="1.15605e-05 1.2167e-05 2.53496e-06 0 -0 5.67932e-07"/>
                  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
                </body>
              </body>
            </body>
          </body>
        </body>
      </body>
      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
      <body name="shoulder_2" pos="-0 0.0505 0.081" quat="0 0 -0.707107 -0.707107">
        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
        <joint axis="0 0 1" name="left_shoulder_pitch" type="hinge" range="-3.141592653589793 3.141592653589793" class="xl330"/>
        <inertial pos="-4.19e-10 2.814e-09 0.00850029" mass="0.00898451" fullinertia="1.06003e-06 1.78233e-06 1.86739e-06 -0 0 0"/>
        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
        <body name="humerus__configuration_left" pos="-0.0145 0 0.0195" quat="0 -0.707107 -0 0.707107">
          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
          <joint axis="0 0 1" name="left_shoulder_roll" type="hinge" range="0.0 3.141592653589793" class="xl330"/>
          <inertial pos="-0.000313281 0.0252784 -0.0143884" mass="0.0416867" fullinertia="1.76899e-05 3.9512e-06 1.75853e-05 3.01684e-07 -5.77e-10 7.6531e-08"/>
          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
          <body name="radius_2" pos="-0.0145 0.0515 -0.0145" quat="0.707107 0 -0.707107 0">
            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
            <joint axis="0 0 1" name="left_elbow" type="hinge" range="-2.1816615649929156 2.1816615649929085" class="xl330"/>
            <inertial pos="-4.0628e-08 0.0310611 -0.0130165" mass="0.0115415" fullinertia="5.26775e-06 1.21602e-06 4.45903e-06 4e-12 1.2e-11 1.7157e-07"/>
            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
          </body>
        </body>
      </body>
      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
      <body name="hip_2" pos="-0 0.036 0" quat="0 -0 0 -1">
        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
        <joint axis="0 0 1" name="left_hip_yaw" type="hinge" range="-1.0471975511965976 4.1887902047863905" class="xl330"/>
        <inertial pos="-0.00421822 -1.46909e-07 -0.00948697" mass="0.00884451" fullinertia="9.36719e-07 4.32505e-06 4.03697e-06 -3.3e-11 -1.95496e-07 -0"/>
        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
        <body name="hip_block__configuration_left" pos="0.02 0 -0.0214" quat="0.5 -0.5 -0.5 0.5">
          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
          <joint axis="0 0 1" name="left_hip_roll" type="hinge" range="-0.6108652381980162 0.6108652381980144" class="xl330"/>
          <inertial pos="6.0554e-05 0.00982795 0.0271548" mass="0.04763" fullinertia="1.64096e-05 1.3312e-05 7.85888e-06 8.495e-09 -7.6959e-08 6.62404e-07"/>
          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
          <body name="femur__configuration_left" pos="-0.0145 -0 0.0385" quat="0.707107 -0 -0.707107 0">
            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
            <joint axis="0 0 1" name="left_hip_pitch" type="hinge" range="-1.5707963267948974 1.5707963267948957" class="xl330"/>
            <inertial pos="0.0109472 0.0366847 -0.0142975" mass="0.014726" fullinertia="1.12665e-05 4.38335e-06 8.95932e-06 -1.12592e-06 1.333e-09 -4.521e-09"/>
            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
            <body name="tibia__configuration_left" pos="0.005 0.062 0" quat="1 -0 -0 -0">
              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

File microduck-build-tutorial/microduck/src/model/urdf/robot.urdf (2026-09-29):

<?xml version="1.0" ?>
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
<robot name="urdf">
  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
  <link name="trunk">
    <inertial>
      <origin xyz="-0.00454781 -0.000104579 0.053896" rpy="0 0 0"/>
      <mass value="0.347283"/>
      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
    </inertial>
    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
  </link>
  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
  <link name="body">
    <origin xyz="0 0 0" rpy="0 -0 0"/>
    <inertial>
      <origin xyz="0 0 0" rpy="0 0 0"/>
      <mass value="1e-9"/>
      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
    </inertial>
  </link>
  <joint name="body_frame" type="fixed">
    <origin xyz="0 0 0" rpy="0 0 0"/>
    <parent link="trunk"/>
    <child link="body"/>
    <axis xyz="0 0 0"/>
  </joint>
  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
  <link name="imu">
    <origin xyz="0 0 0" rpy="0 -0 0"/>
    <inertial>
      <origin xyz="0 0 0" rpy="0 0 0"/>
      <mass value="1e-9"/>
      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
    </inertial>
  </link>
  <joint name="imu_frame" type="fixed">
    <origin xyz="0.01483 -0.002 0.0675" rpy="1.5708 -0 -1.5708"/>
    <parent link="trunk"/>
    <child link="imu"/>
    <axis xyz="0 0 0"/>
  </joint>
  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
  <link name="head">
    <inertial>
      <origin xyz="5.1303e-08 -0.0074561 0.0161837" rpy="0 0 0"/>
      <mass value="0.0166215"/>
      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
    </inertial>
    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
  </link>
  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
  <joint name="head" type="revolute">
    <origin xyz="-0.00204165 -0 0.126" rpy="0 0 1.5708"/>
    <parent link="trunk"/>
    <child link="head"/>
    <axis xyz="0 0 1"/>
    <limit effort="10" velocity="10" lower="-1.5708" upper="1.5708"/>
  </joint>
  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
  <link name="shoulder">
    <inertial>
      <origin xyz="4.19e-10 2.814e-09 -0.00850029" rpy="0 0 0"/>
      <mass value="0.00898451"/>
      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
    </inertial>
    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
  </link>
  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
  <link name="humerus__configuration_right">
    <inertial>
      <origin xyz="-0.000309872 -0.0252784 -0.0143918" rpy="0 0 0"/>
      <mass value="0.0416867"/>
      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
    </inertial>
    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
  </link>
  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
  <link name="radius">
    <inertial>
      <origin xyz="-4.0628e-08 -0.0310611 0.0130165" rpy="0 0 0"/>
      <mass value="0.0115415"/>
      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
    </inertial>
    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
  </link>
  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
  <joint name="right_elbow" type="revolute">
    <origin xyz="-0.0145 -0.0515 -0.0145" rpy="-0 1.5708 0"/>
    <parent link="humerus__configuration_right"/>
    <child link="radius"/>
    <axis xyz="0 0 1"/>
    <limit effort="10" velocity="10" lower="-2.18166" upper="2.18166"/>
  </joint>
  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
  <joint name="right_shoulder_roll" type="revolute">
    <origin xyz="0.0145 0 -0.0195" rpy="-3.14159 -1.5708 0"/>
    <parent link="shoulder"/>
    <child link="humerus__configuration_right"/>
    <axis xyz="0 0 1"/>
    <limit effort="10" velocity="10" lower="-3.14159" upper="0"/>
  </joint>
  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
  <joint name="right_shoulder_pitch" type="revolute">
    <origin xyz="0 -0.0505 0.081" rpy="-1.5708 0 0"/>
    <parent link="trunk"/>
    <child link="shoulder"/>
    <axis xyz="0 0 1"/>
    <limit effort="10" velocity="10" lower="-3.14159" upper="3.14159"/>
  </joint>
  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
  <link name="hip">
    <inertial>
      <origin xyz="0.00421822 1.46909e-07 -0.00948697" rpy="0 0 0"/>
      <mass value="0.00884451"/>
      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
    </inertial>
    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
  </link>
  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
  <link name="hip_block__configuration_right">
    <inertial>
      <origin xyz="-5.75932e-05 0.00982795 0.0271518" rpy="0 0 0"/>
      <mass value="0.04763"/>
      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
    </inertial>
    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
  </link>
  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
  <link name="femur__configuration_right">
    <inertial>
      <origin xyz="-0.0109472 -0.0366847 -0.0147025" rpy="0 0 0"/>
      <mass value="0.014726"/>
      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
    </inertial>
    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
  </link>
  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
  <link name="tibia__configuration_right">
    <inertial>
      <origin xyz="0.00276278 -0.0196679 -0.0144621" rpy="0 0 0"/>
      <mass value="0.0300463"/>
      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
    </inertial>
    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
  </link>
  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
  <link name="ankle_block__configuration_left">
    <inertial>
      <origin xyz="-0.0110676 -0.00979852 -0.0144015" rpy="0 0 0"/>
      <mass value="0.04722"/>
      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
    </inertial>
    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
  </link>
  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
  <link name="foot">
    <inertial>
      <origin xyz="-0 -0.0168869 0.0347422" rpy="0 0 0"/>
      <mass value="0.016823"/>
      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
    </inertial>
    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
  </link>
  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
  <link name="right_foot">
    <origin xyz="0 0 0" rpy="0 -0 0"/>
    <inertial>
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

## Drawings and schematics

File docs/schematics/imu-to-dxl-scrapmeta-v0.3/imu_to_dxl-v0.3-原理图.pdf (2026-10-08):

# MCU

# 六轴 IMU（加速度计 + 陀螺仪）

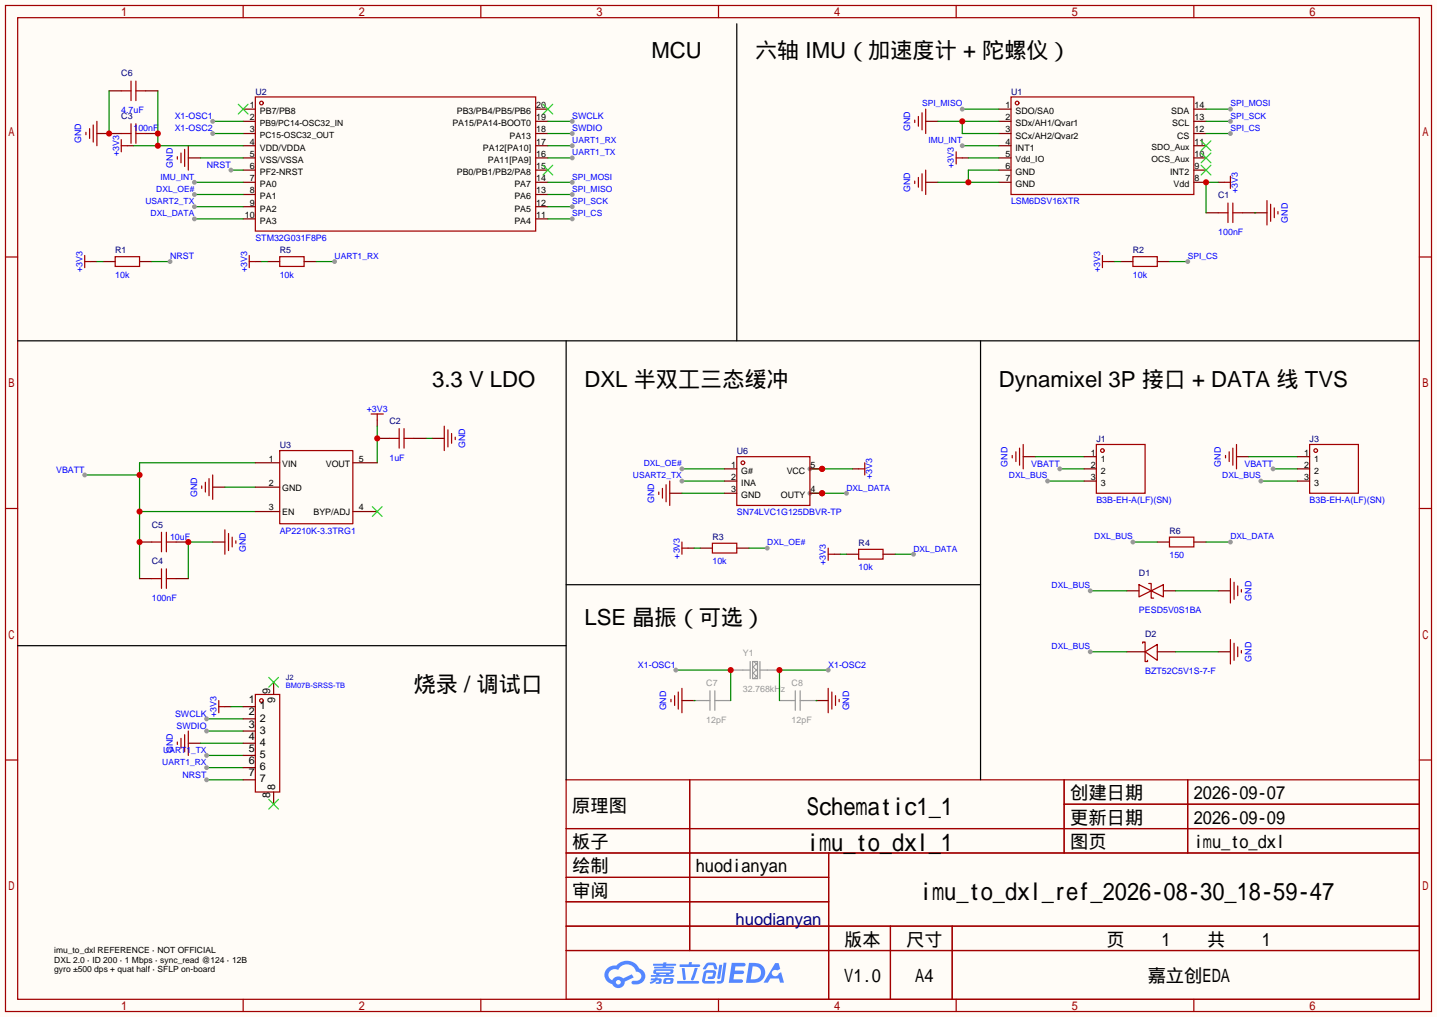
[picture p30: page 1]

Dynamixel 3P 接口 + DATA 线 TVS

原理图 | Schematic1_1 | 创建日期 | 2026-09-07

更新日期 | 2026-09-09

板子 | imu_to_dxl_1 | 图页 | imu_to_dxl
绘制 | huodianyan | imu_to_dxl_ref_2026-08-30_18-59-47
审阅

huodianyan

imu_to_dxl REFERENCE · NOT OFFICIAL
DXL 2.0 · ID 200 · 1 Mbps · sync_read @124 · 12B
gyro ±500 dps + quat half · SFLP on-board

V1.0 | A4 | 嘉立创EDA

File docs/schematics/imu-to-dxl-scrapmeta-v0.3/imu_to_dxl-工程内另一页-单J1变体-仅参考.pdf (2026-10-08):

# MCU

# 六轴 IMU（加速度计 + 陀螺仪）

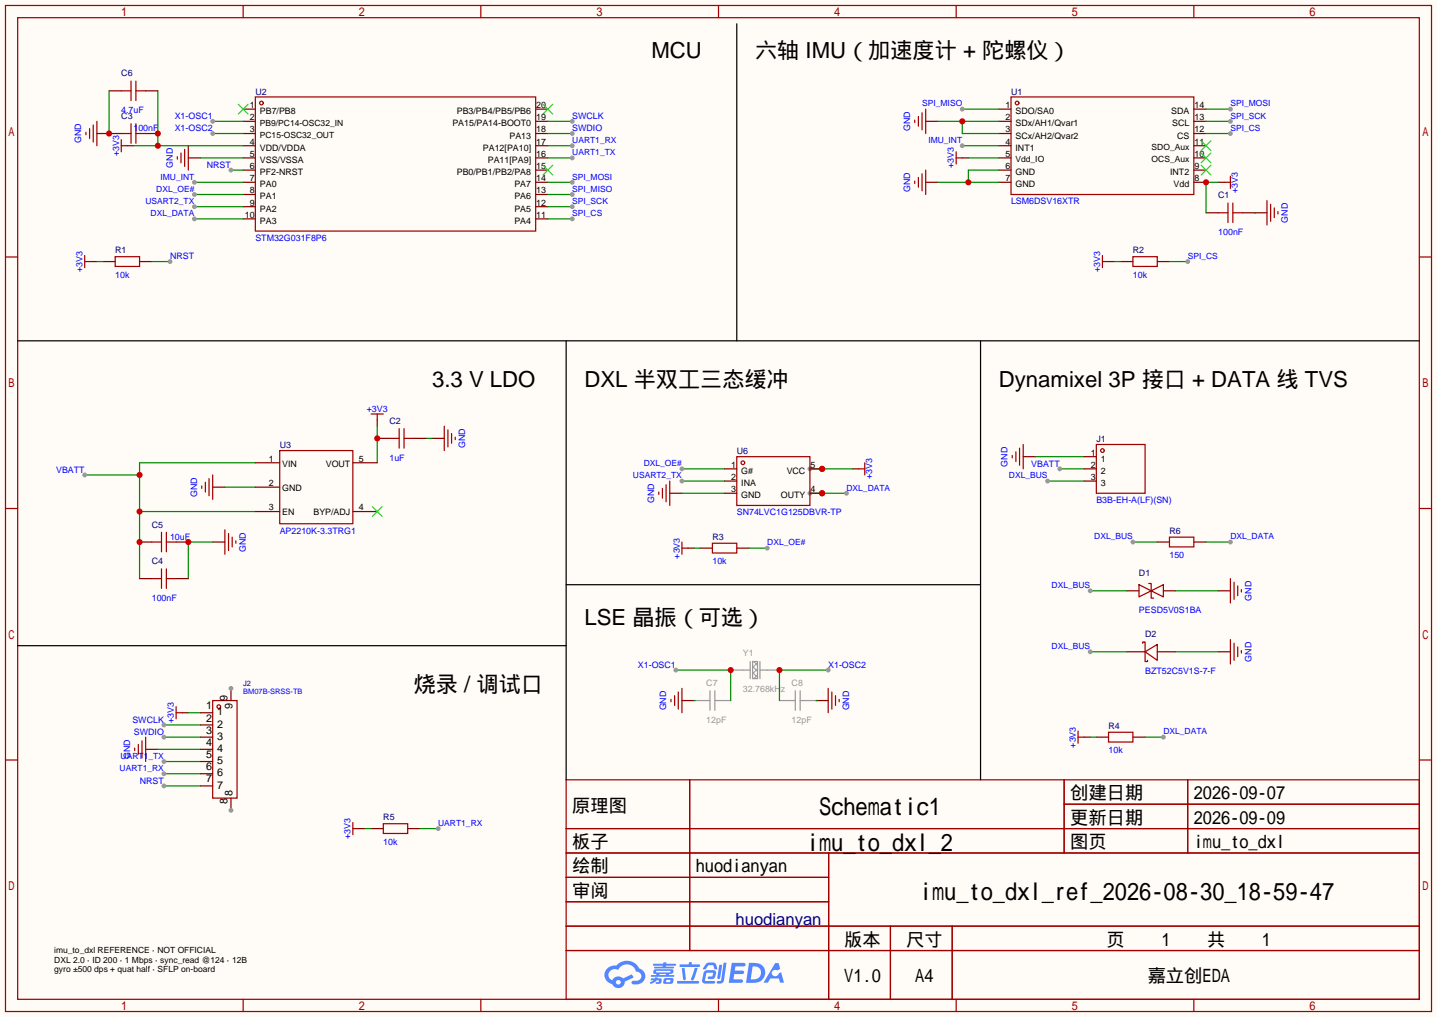
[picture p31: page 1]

Dynamixel 3P 接口 + DATA 线 TVS

原理图 | Schematic1 | 创建日期 | 2026-09-07

更新日期 | 2026-09-09

板子 | imu_to_dxl_2 | 图页 | imu_to_dxl
绘制 | huodianyan | imu_to_dxl_ref_2026-08-30_18-59-47
审阅

huodianyan

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

V1.0 | A4 | 嘉立创EDA

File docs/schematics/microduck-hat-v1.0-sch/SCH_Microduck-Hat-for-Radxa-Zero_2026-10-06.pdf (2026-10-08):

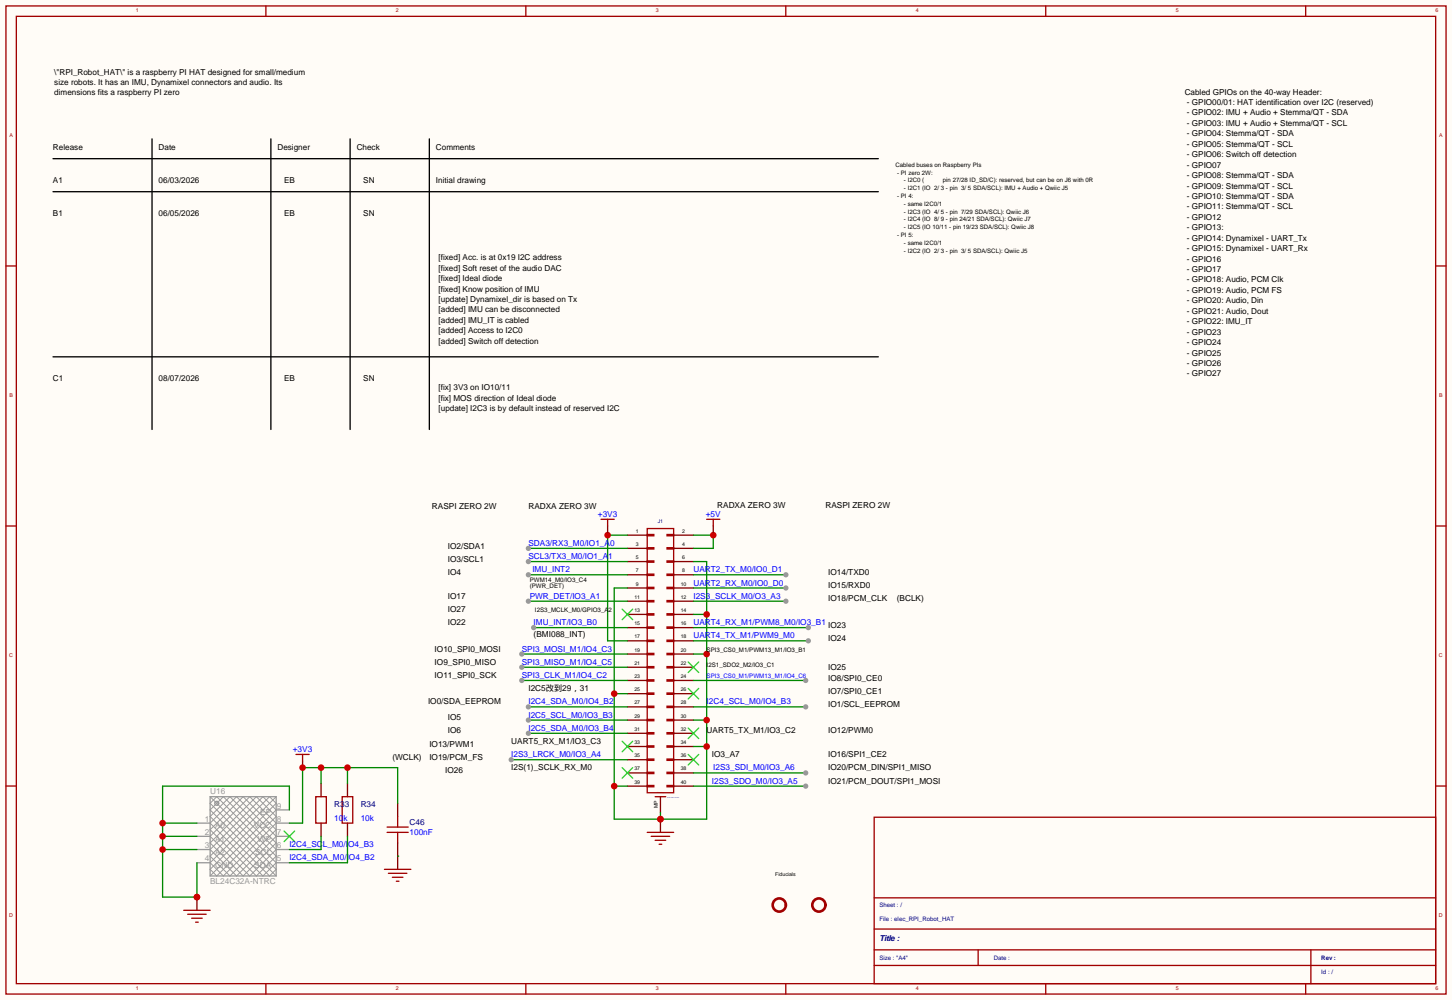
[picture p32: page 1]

\"RPI_Robot_HAT\" is a raspberry PI HAT designed for small/medium
size robots. It has an IMU, Dynamixel connectors and audio. Its
dimensions fits a raspberry PI zero

Cabled buses on Raspberry PIs
- PI zero 2W:
- I2C1 (IO 2/ 3 - pin 3/ 5 SDA/SCL): IMU + Audio + Qwiic J5
- same I2C0/1
- I2C3 (IO 4/ 5 - pin 7/29 SDA/SCL): Qwiic J6
- I2C4 (IO 8/ 9 - pin 24/21 SDA/SCL): Qwiic J7
- I2C5 (IO 10/11 - pin 19/23 SDA/SCL): Qwiic J8
- I2C2 (IO 2/ 3 - pin 3/ 5 SDA/SCL): Qwiic J5

[fixed] Acc. is at 0x19 I2C address
[fixed] Soft reset of the audio DAC
[fixed] Ideal diode
[fixed] Know position of IMU
[update] Dynamixel_dir is based on Tx
[added] IMU can be disconnected
[added] IMU_IT is cabled
[added] Access to I2C0
[added] Switch off detection

[fix] 3V3 on IO10/11
[fix] MOS direction of Ideal diode
[update] I2C3 is by default instead of reserved I2C

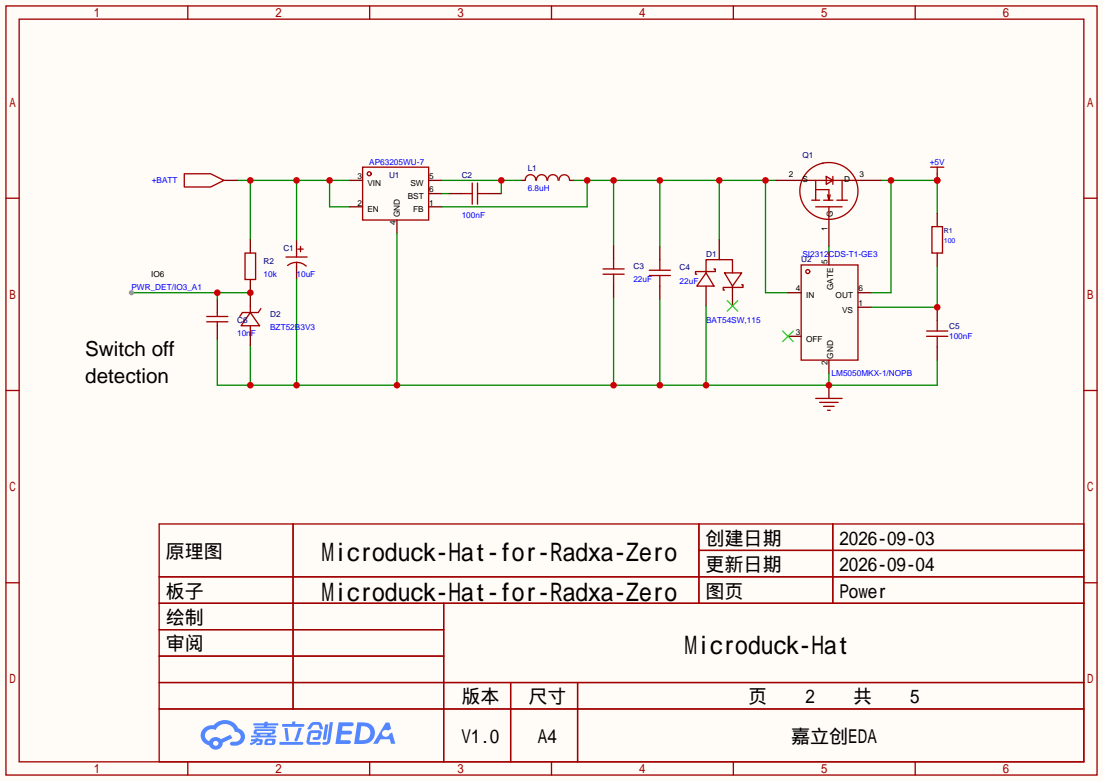
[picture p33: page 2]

原理图 | Microduck-Hat-for-Radxa-Zero | 创建日期 | 2026-09-03

更新日期 | 2026-09-04

板子 | Microduck-Hat-for-Radxa-Zero | 图页 | Power
绘制 | | Microduck-Hat
审阅

V1.0 | A4 | 嘉立创EDA

# I2C SENSOR BUS

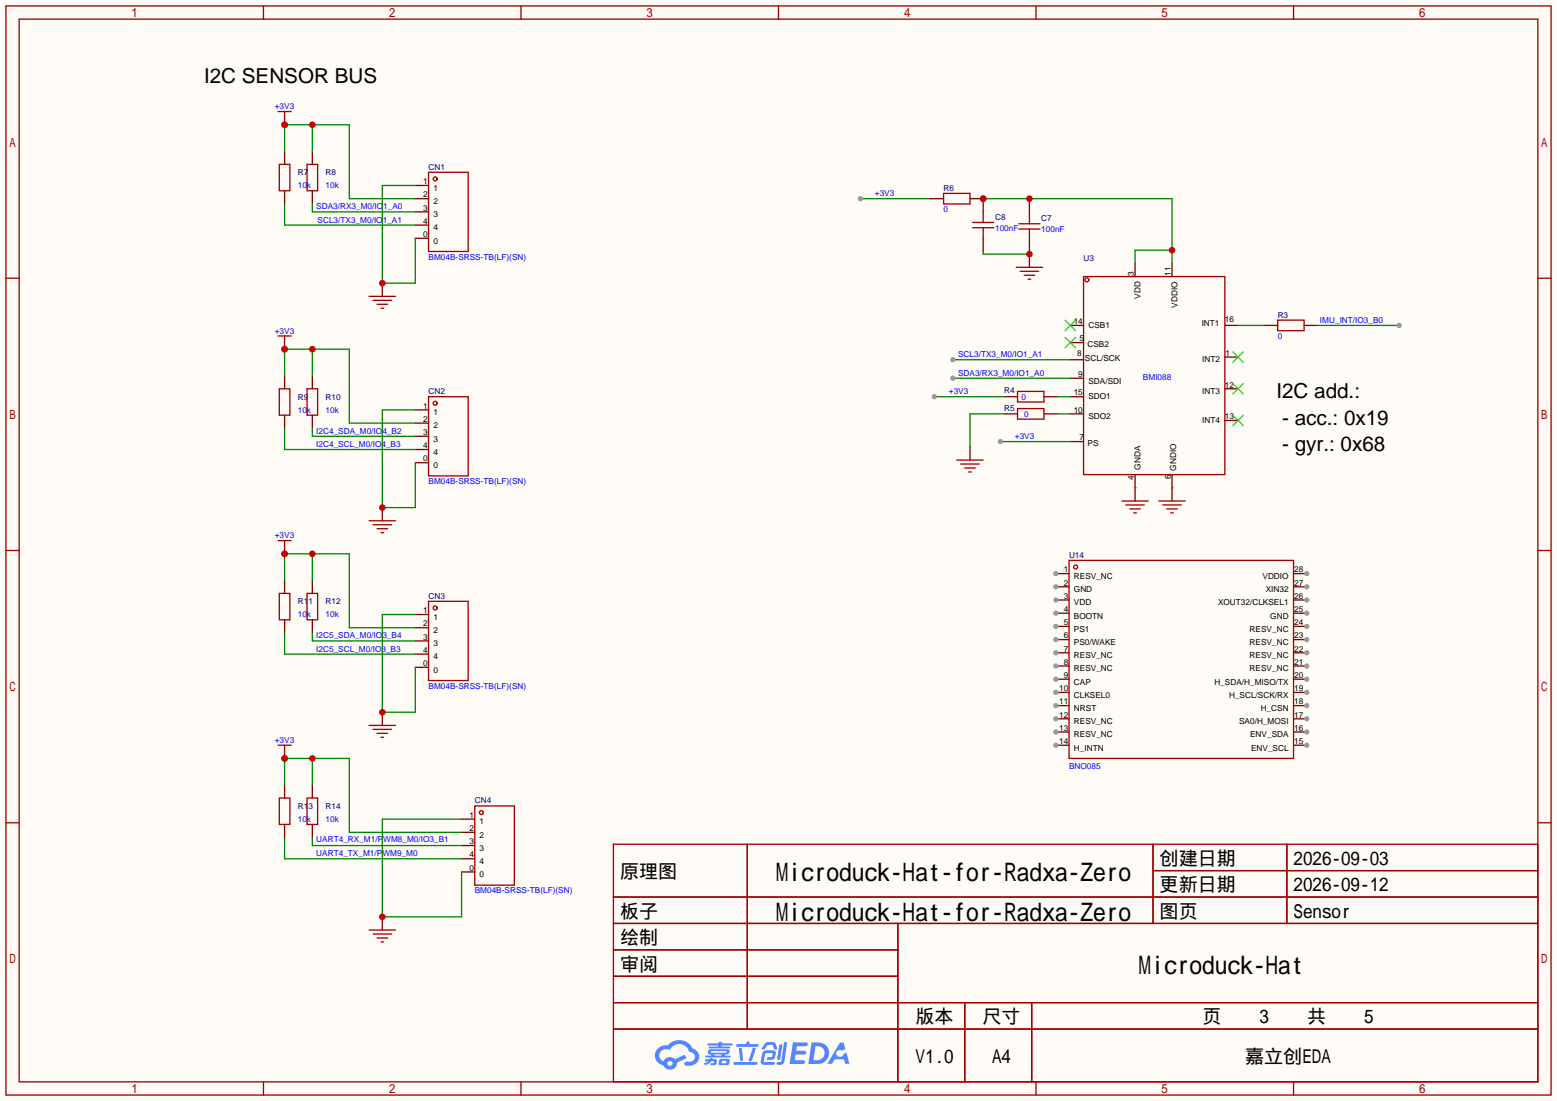
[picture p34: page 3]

原理图 | Microduck-Hat-for-Radxa-Zero | 创建日期 | 2026-09-03

更新日期 | 2026-09-12

板子 | Microduck-Hat-for-Radxa-Zero | 图页 | Sensor
绘制 | | Microduck-Hat
审阅

# SERVOS

IO14

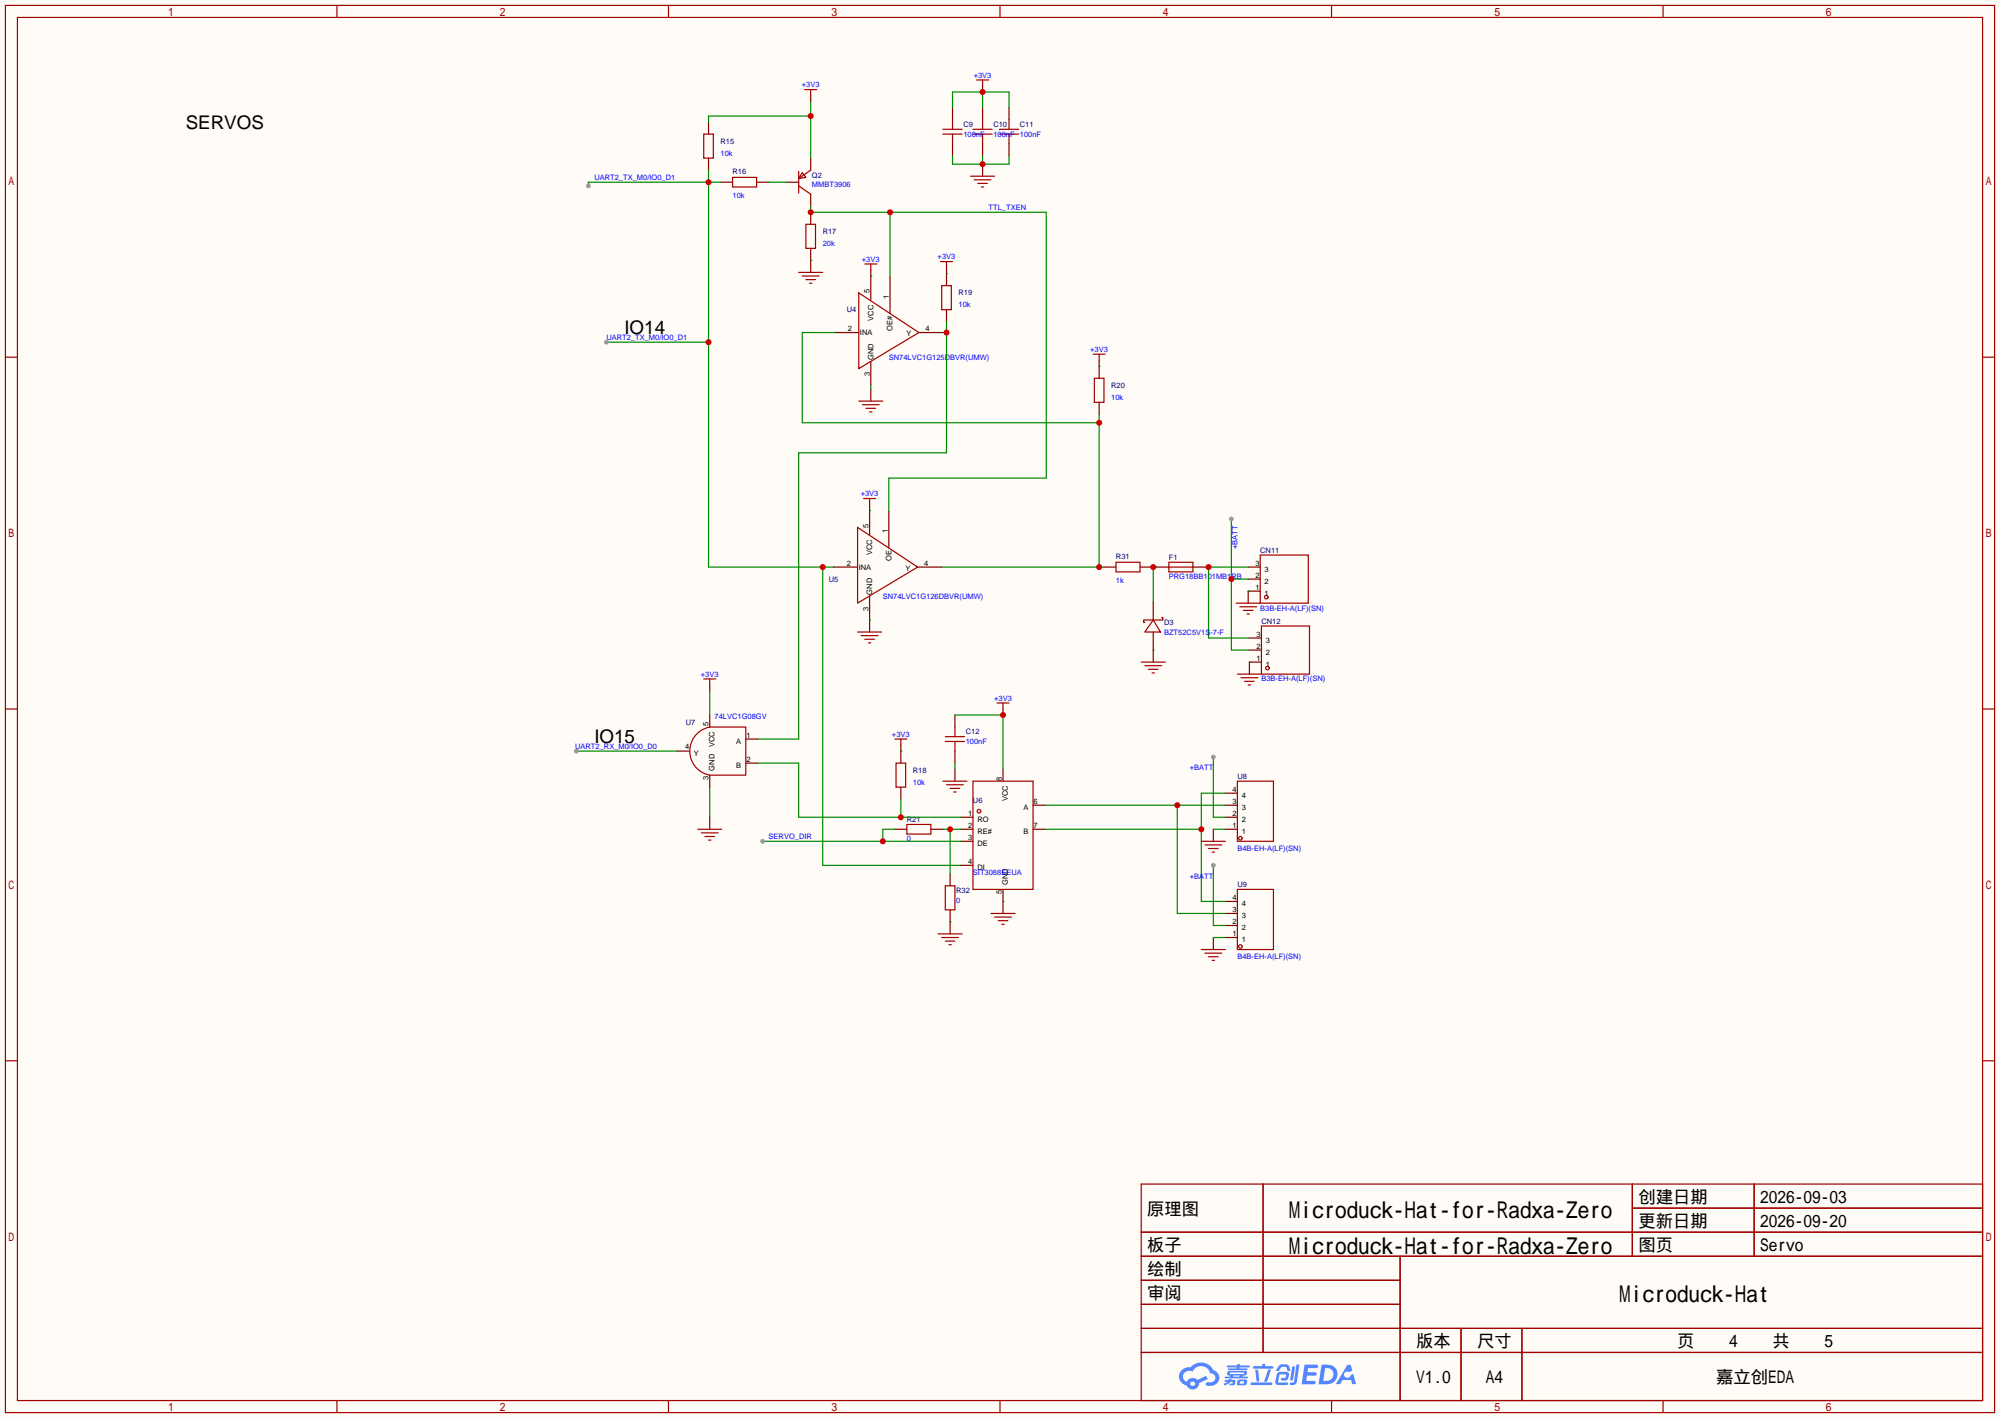
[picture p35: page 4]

原理图 | Microduck-Hat-for-Radxa-Zero | 创建日期 | 2026-09-03

更新日期 | 2026-09-20

板子 | Microduck-Hat-for-Radxa-Zero | 图页 | Servo
绘制 | | Microduck-Hat
审阅

# I2C address: 0x18

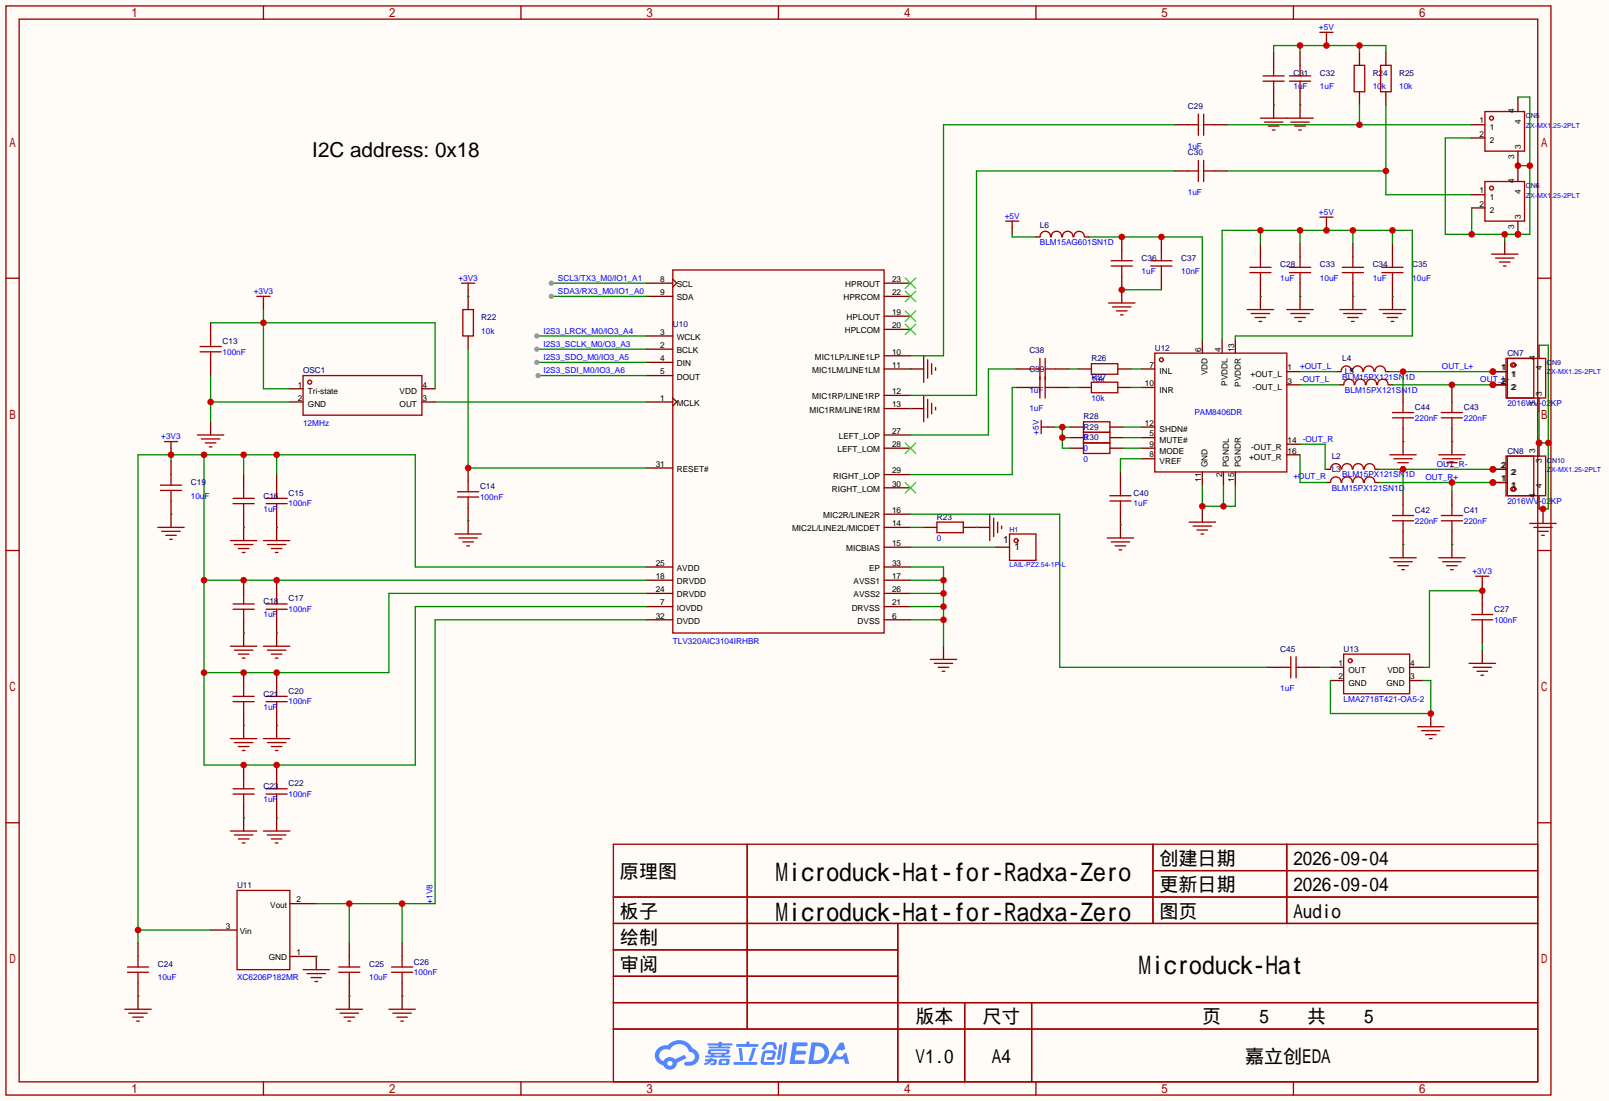
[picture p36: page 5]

原理图 | Microduck-Hat-for-Radxa-Zero | 创建日期 | 2026-09-04

更新日期 | 2026-09-04

板子 | Microduck-Hat-for-Radxa-Zero | 图页 | Audio
绘制 | | Microduck-Hat
审阅

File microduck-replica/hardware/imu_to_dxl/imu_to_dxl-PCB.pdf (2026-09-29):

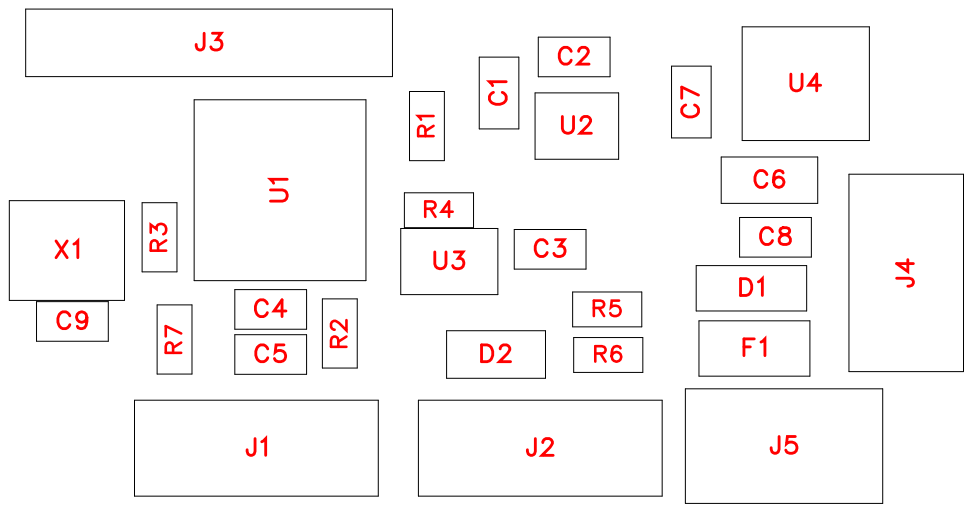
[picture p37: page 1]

No. | Quantity | Comment | Designator | Footprint | Value | Manufacturer Part | Manufacturer | Supplier Part | Supplier
1 | 6 | 100nF | C1,C2,C3,C4,C8,C9 | C0603 | 100nF | CC0603KRX 7R9BB104 | YAGEO(国巨 ) | C14663 | LCSC
2 | 1 | 4.7uF/16V | C5 | C0603 | 4.7uF/16V | CL10A475K O8NNNC | SAMSUNG( ) 三星 | C19666 | LCSC
3 | 1 | 10uF/25V | C6 | C0805 | 10uF/25V | CL21A106KA YNNNE | SAMSUNG( 三星 ) | C15850 | LCSC
4 | 1 | 10uF/10V | C7 | C0603 | 10uF/10V | CL10A106KP 8NNNC | SAMSUNG( 三星 ) | C19702 | LCSC
5 | 1 | SMF12A | D1 | SOD-123FL_ L2.7-W1.8-L S3.7-RD | | SMF12A | GOODWOR K(固得沃克 ) | C2943870 | LCSC
6 | 1 | BZT52C5V1-7-F | D2 | SOD-123_L2 .7-W1.6-LS3. 7-RD | 5V1 | BZT52C5V1-7-F | DIODES( 美 台 ) | C151588 | LCSC
7 | 1 | MF-NSMF02 0X-2 | F1 | F1206 | | MF-NSMF02 0X-2 | BOURNS | C210358 | LCSC
8 | 1 | 舵机总线进 | J1 | CONN-TH_B 3B-EH-A-LF-SN | | B3B-EH-A(L F)(SN) | JST | C160259 | LCSC
9 | 1 | 舵机总出线 | J2 | CONN-TH_B 3B-EH-A-LF-SN | | B3B-EH-A(L F)(SN) | JST | C160259 | LCSC
10 | 1 | PZ254V-11-0 6P | J3 | HDR-TH_6P-P2.54-V-M | | PZ254V-11-0 6P | XFCN(兴飞 ) | C492405 | LCSC
11 | 1 | 飞特总线进 | J4 | CONN-TH_B 3B-PH-K-S | | B3B-PH-K-S( LF)(SN) | JST | C131339 | LCSC
12 | 1 | 飞特总线出 | J5 | CONN-TH_B 3B-PH-K-S | | B3B-PH-K-S( LF)(SN) | JST | C131339 | LCSC
13 | 5 | 10k | R1,R2,R4,R5,R7 | R0603 | 10k | 0603WAF10 02T5E | UNI-ROYAL( 厚声 ) | C25804 | LCSC
14 | 1 | 33R | R3 | R0603 | 33R | 0603WAF33 0JT5E | UNI-ROYAL( ) 厚声 | C23140 | LCSC
15 | 1 | 150R | R6 | R0603 | 150R | 0603WAF15 00T5E | UNI-ROYAL( ) 厚声 | C22808 | LCSC
16 | 1 | STM32G031 F8P6 | U1 | TSSOP-20_L 6.5-W4.4-P0. 65-LS6.4-BL | | STM32G031 F8P6 | ST(意法半导 体) | C529334 | LCSC
17 | 1 | LSM6DSV16 XTR | U2 | LGA-14_L3.0 -W2.5-P0.50-BR | | LSM6DSV16 XTR | ST(意法半导 体) | C5267406 | LCSC
18 | 1 | SN74LVC2G 241DCUR | U3 | VSSOP-8_L2 .3-W2.0-P0.5 0-LS3.1-BR | | SN74LVC2G 241DCUR | TI(德州仪器 ) | C10430 | LCSC
19 | 1 | HT7533-1 | U4 | SOT-89-3_L4 .5-W2.5-P1.5 0-LS4.2-BR | | HT7533-1 | HOLTEK( 合 泰 /盛群 ) | C14289 | LCSC

20

1 | 16MHz | X1 | OSC-SMD_4 P-L3.2-W2.5- BL_SIT8008 BI
16MHz | S3D16.0000
00B20F30T

SCTF(星通时 频)

C387369 LCSC

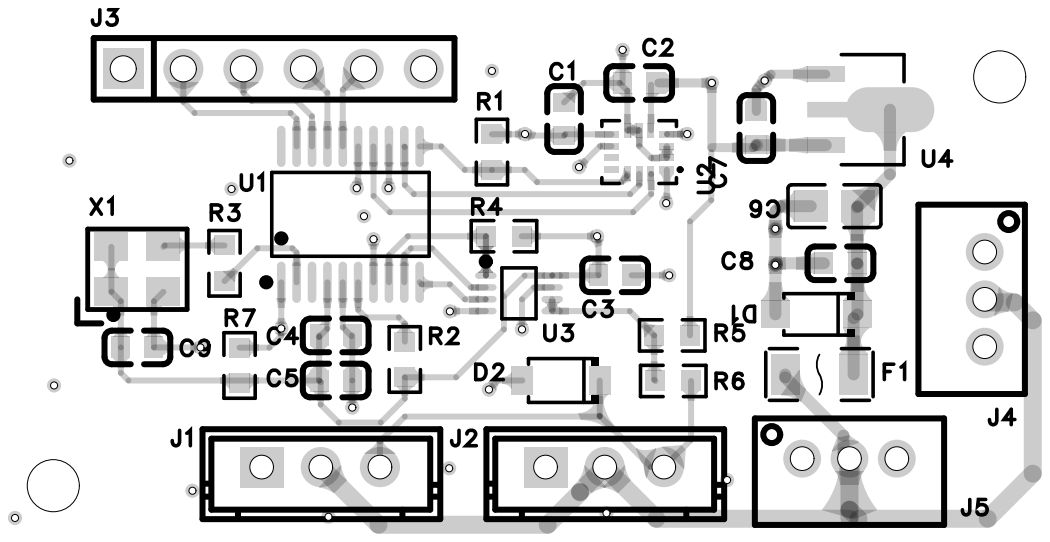
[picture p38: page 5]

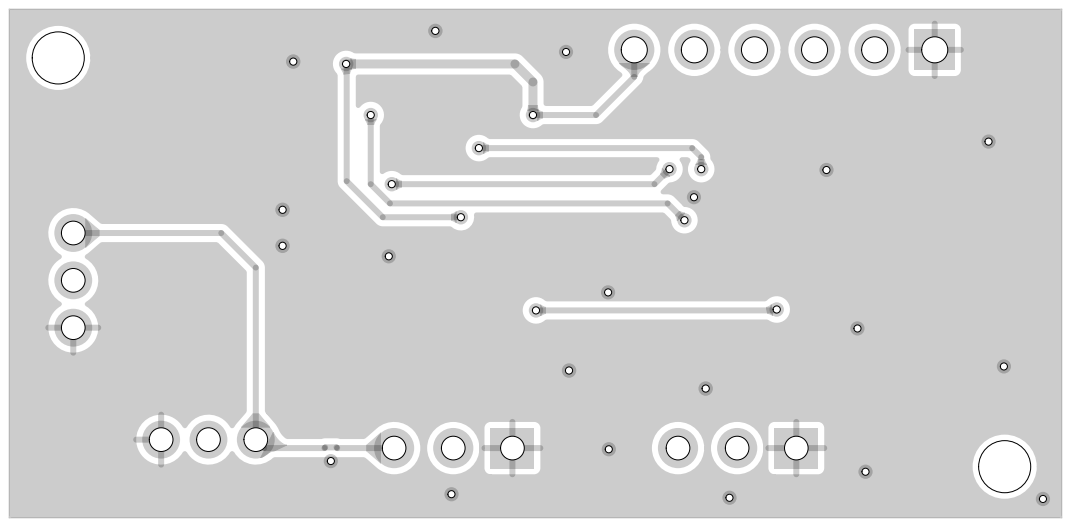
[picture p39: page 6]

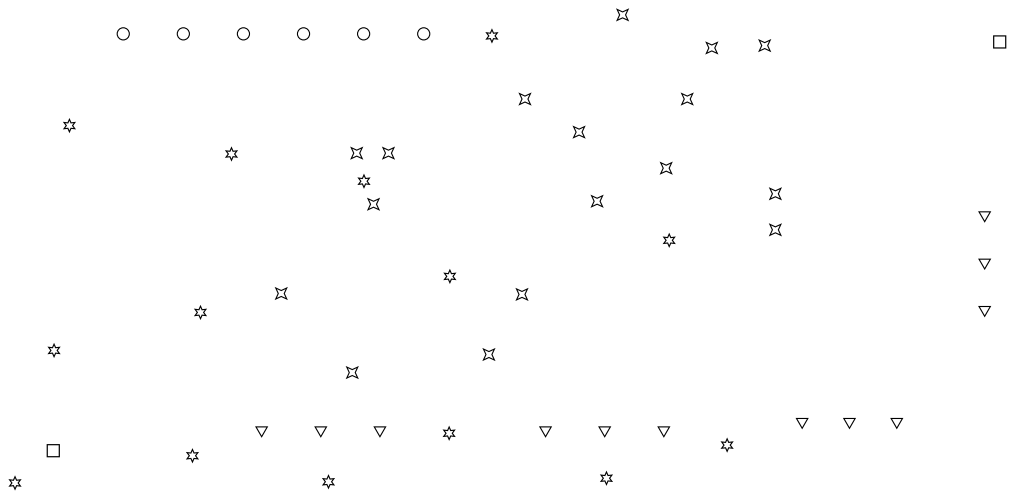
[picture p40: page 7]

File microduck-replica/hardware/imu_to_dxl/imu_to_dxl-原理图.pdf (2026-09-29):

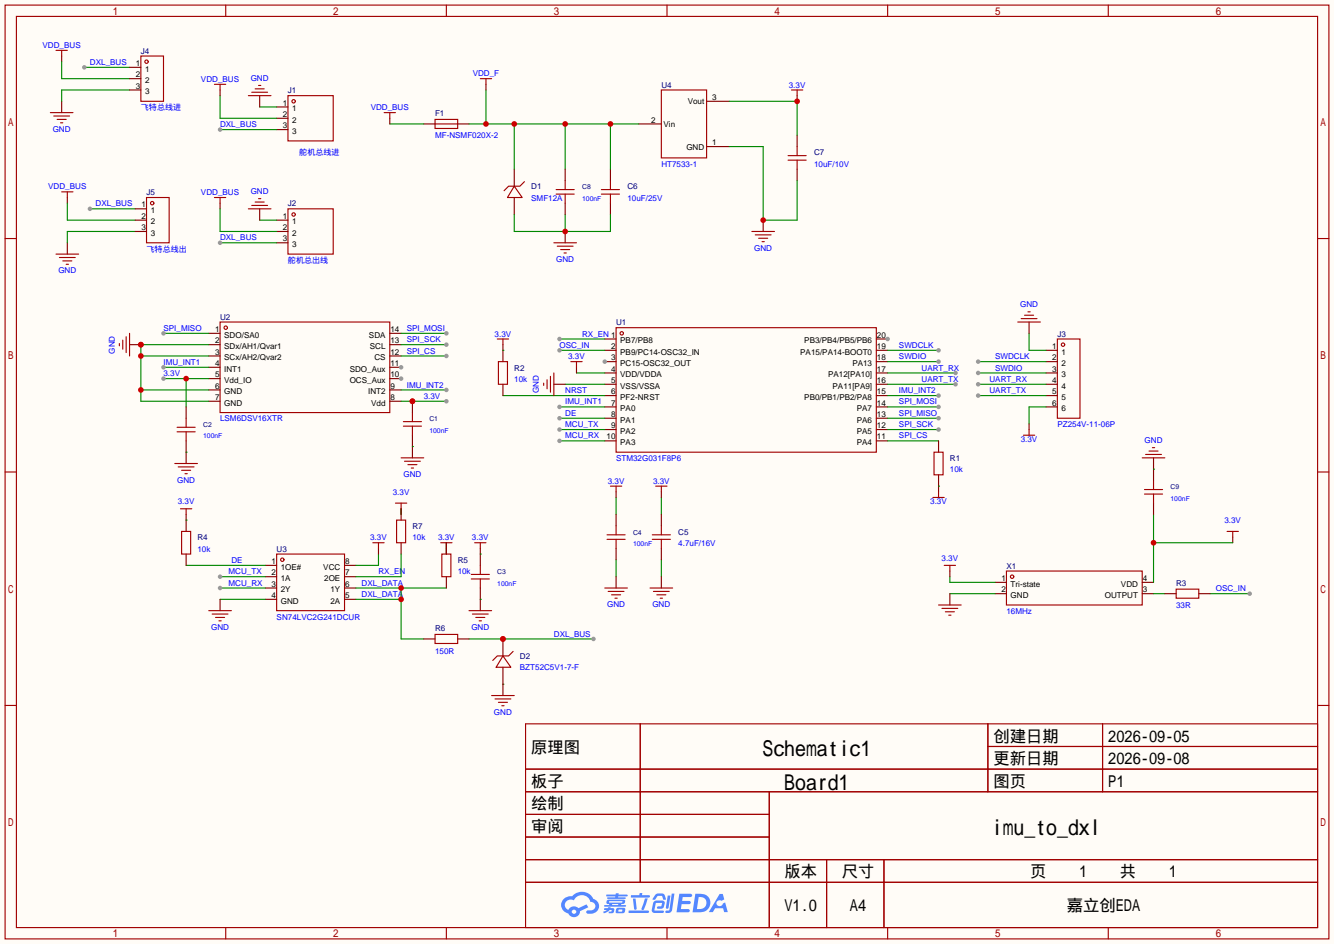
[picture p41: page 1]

原理图 | Schematic1 | 创建日期 | 2026-09-05

更新日期 | 2026-09-08

板子 | Board1 | 图页 | P1
绘制 | | imu_to_dxl
审阅

V1.0 | A4 | 嘉立创EDA

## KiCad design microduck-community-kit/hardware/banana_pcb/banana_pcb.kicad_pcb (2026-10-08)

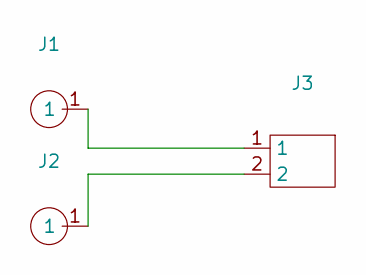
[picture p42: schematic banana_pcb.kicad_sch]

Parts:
J1, J2: banana_pin
J3: pad-2(surf)

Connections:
unnamed: J1.1, J3.1
unnamed: J2.1, J3.2

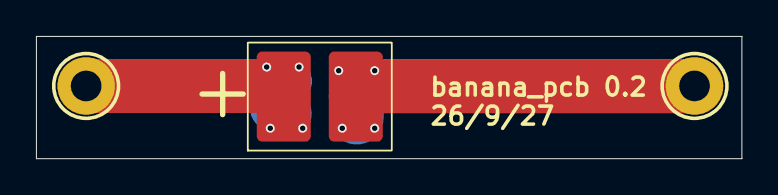
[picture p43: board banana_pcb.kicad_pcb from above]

Board: 2 copper layers, 39.2 x 6.8 mm, 3 parts (0 on the bottom side), 2 nets.

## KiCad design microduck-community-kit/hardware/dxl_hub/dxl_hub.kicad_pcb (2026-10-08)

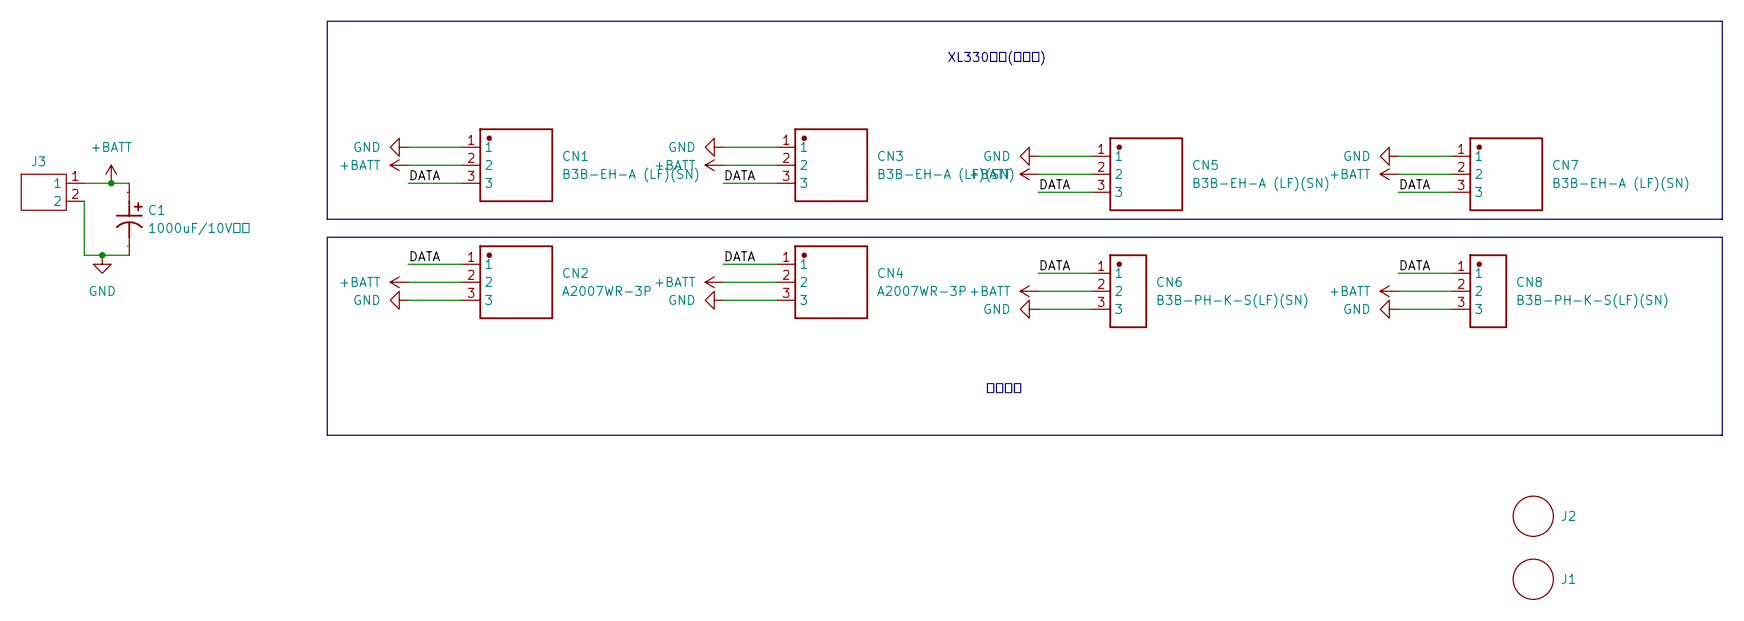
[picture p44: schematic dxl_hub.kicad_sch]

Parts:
C1: 1000uF/10V固态; CAP-TH_BD8.0-P3.50-D0.5-FD; Manufacturer Part SPZ1AM102F11000RAXXX
CN1, CN3, CN5, CN7: B3B-EH-A (LF)(SN); CONN-TH_B3B-EH-A-LF-SN
CN2, CN4: A2007WR-3P; CONN-TH_A2007WR-3P; Manufacturer Part A2007WR-3P
CN6, CN8: B3B-PH-K-S(LF)(SN); CONN-TH_B3B-PH-K-S
J1, J2: 1.8mm螺丝孔; pad
J3: pad-2(thru)

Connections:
+BATT: C1.1, CN1.2, CN2.2, CN3.2, CN4.2, CN5.2, CN6.2, CN7.2, CN8.2, J3.1
/DATA: CN1.3, CN2.1, CN3.3, CN4.1, CN5.3, CN6.1, CN7.3, CN8.1
GND: C1.2, CN1.1, CN2.3, CN3.1, CN4.3, CN5.1, CN6.3, CN7.1, CN8.3, J3.2

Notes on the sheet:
飞特接口
XL330接口(二选一)

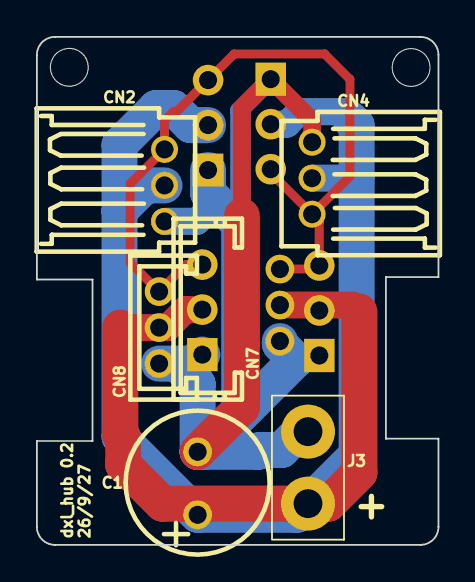
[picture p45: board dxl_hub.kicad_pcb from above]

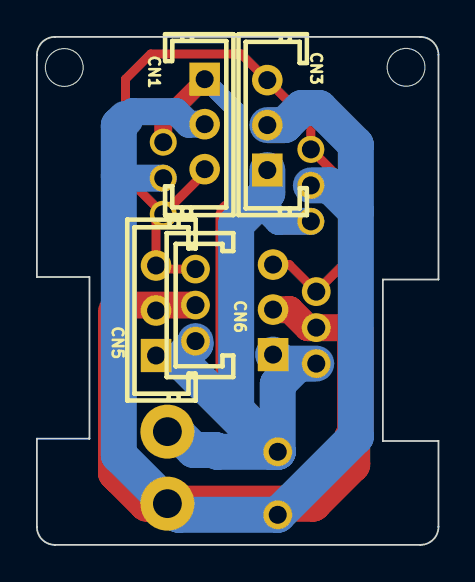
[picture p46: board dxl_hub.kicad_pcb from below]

Board: 2 copper layers, 22.3 x 28.2 mm, 12 parts (4 on the bottom side), 3 nets.

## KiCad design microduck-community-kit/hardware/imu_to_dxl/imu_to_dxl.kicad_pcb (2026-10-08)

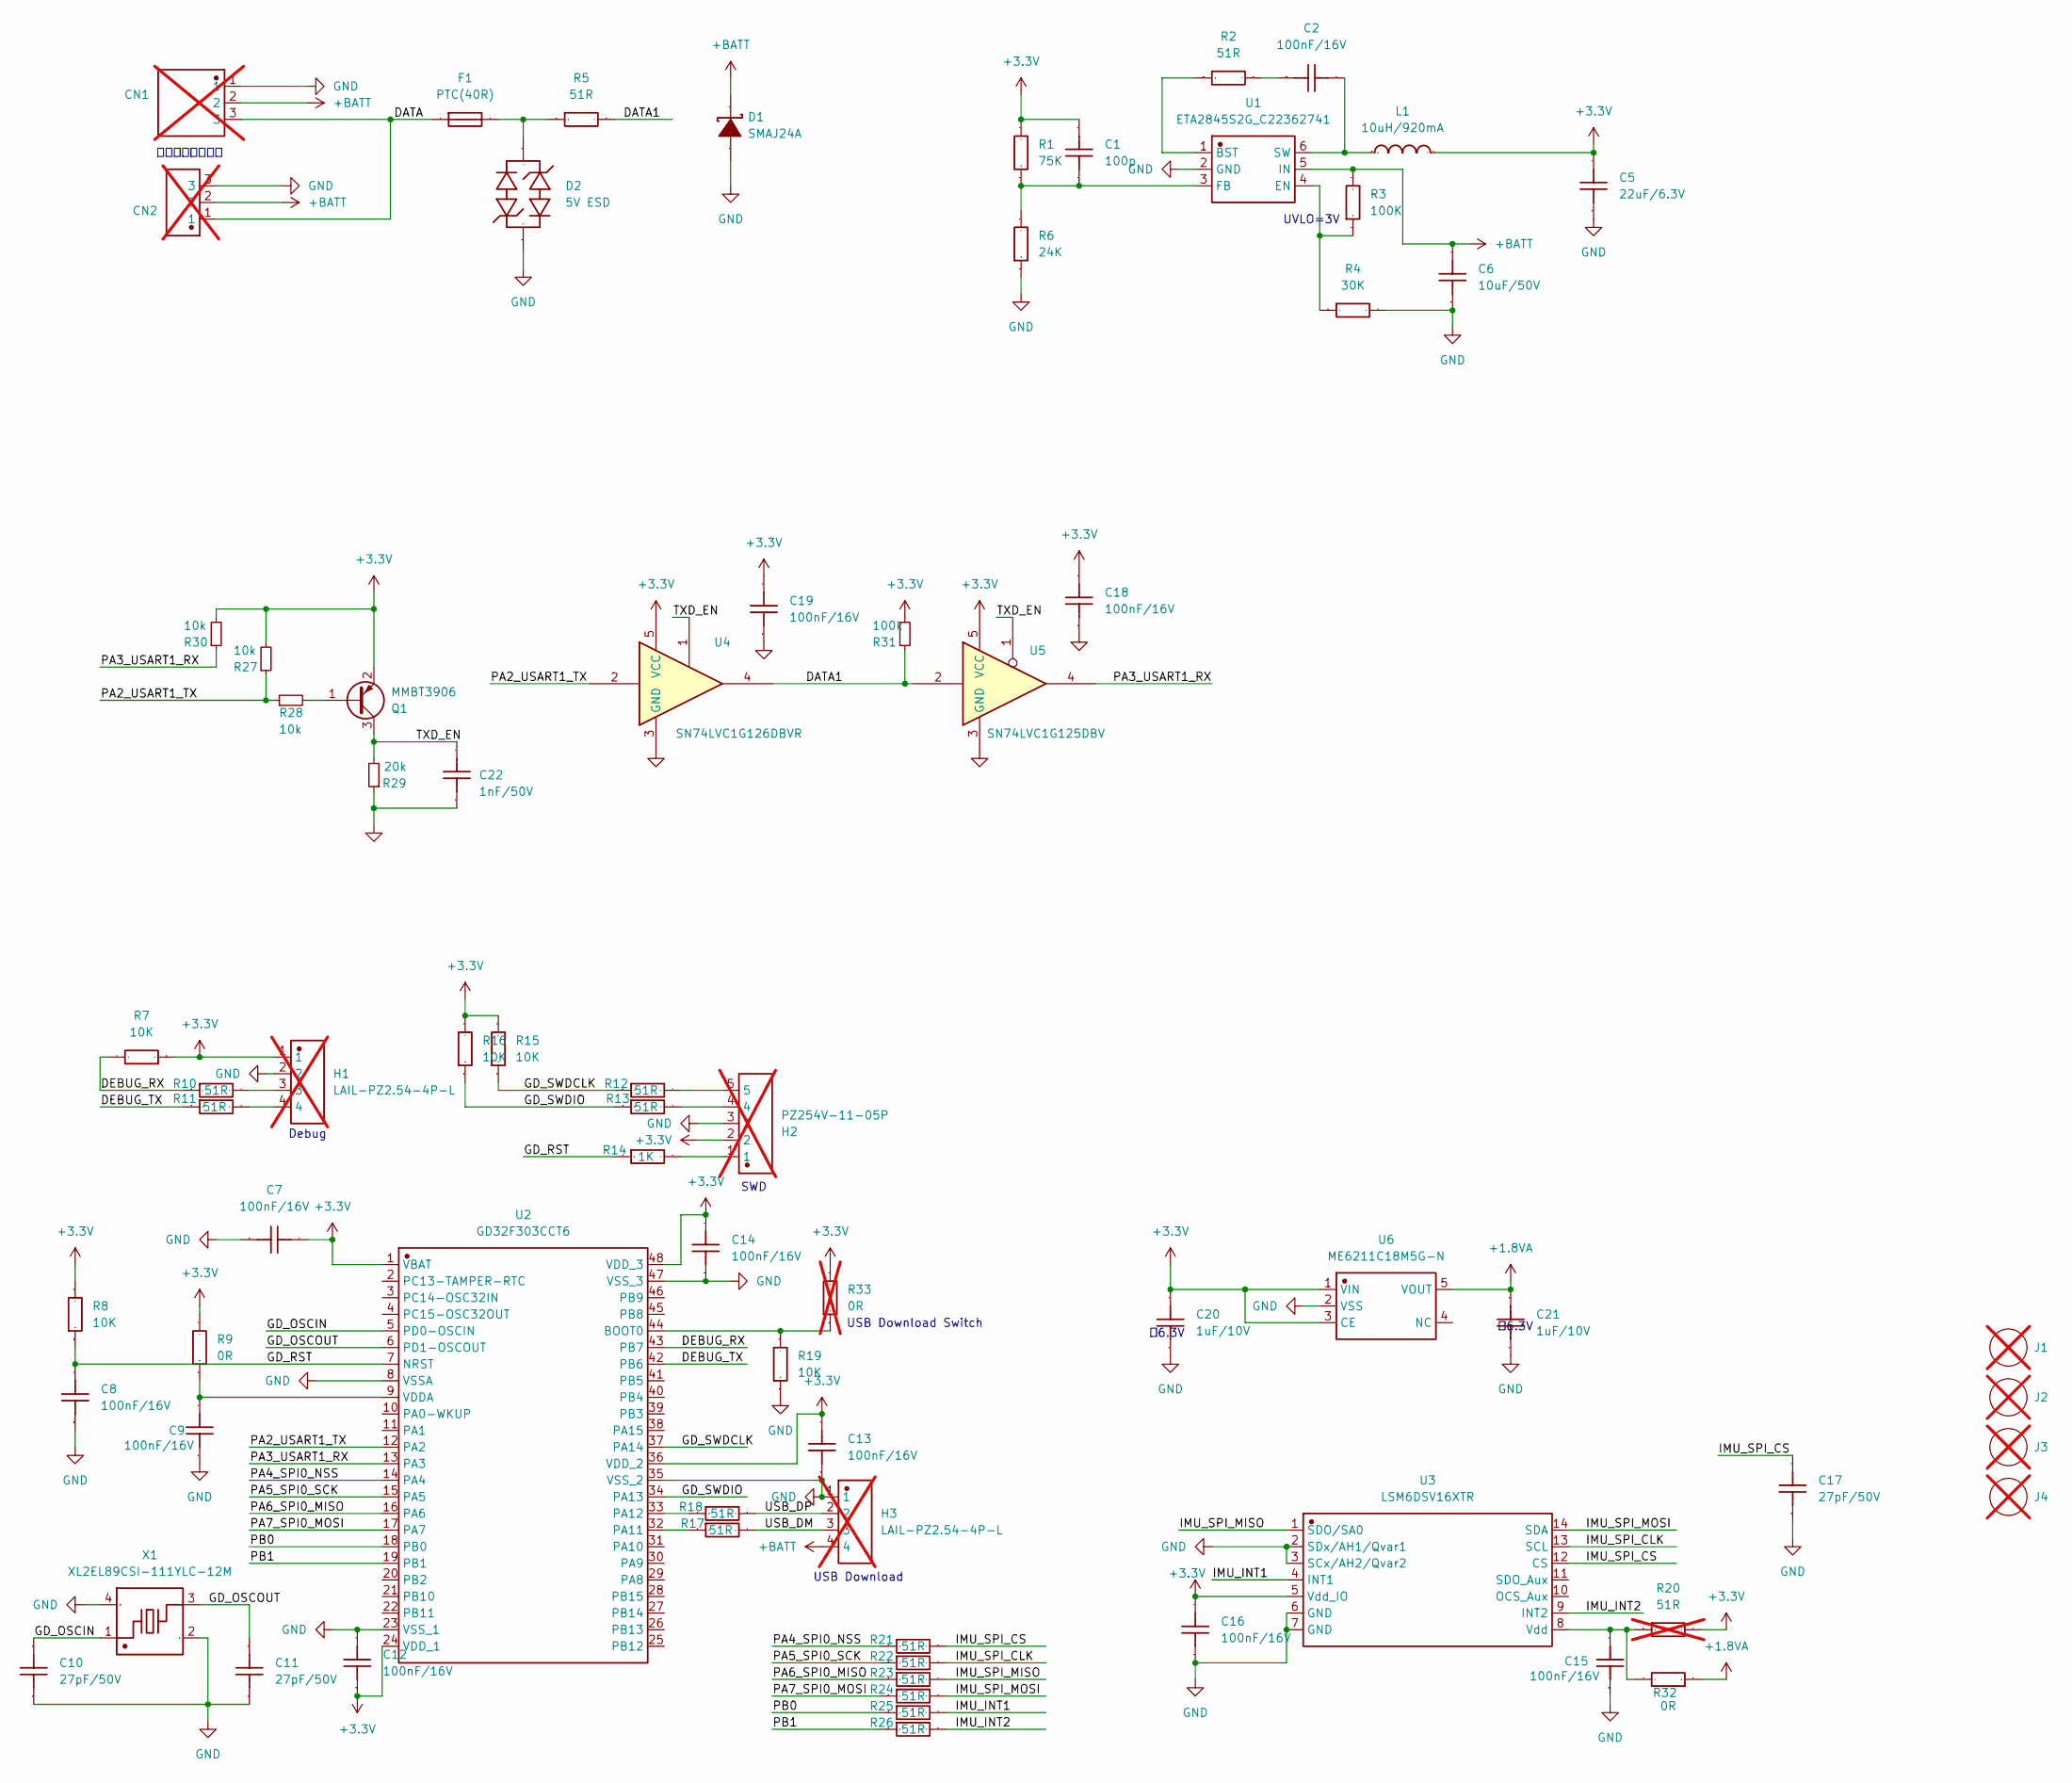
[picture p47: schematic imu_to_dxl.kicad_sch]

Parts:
C1: 100p; C0402; LCSC Part C106200
C2, C7, C8, C9, C12, C13, C14, C15, C16, C18, C19: 100nF/16V; C0402; LCSC Part C1525
C5: 22uF/6.3V; C0603; LCSC Part C59461
C6: 10uF/50V; C0805; Manufacturer Part CL21A106KBYQNNE; LCSC Part C2932476
C10, C11, C17: 27pF/50V; C0402; LCSC Part C107002
C20, C21: 1uF/10V; C0402; LCSC Part C106254
C22: 1nF/50V; C0402; LCSC Part C106205
CN1: CONN-TH_B3B-EH-A-LF-SN; not fitted
CN2: CONN-TH_B3B-PH-K-S; not fitted
D1: SMAJ24A; SMA_L4.4-W2.6-LS5.0-RD; Manufacturer Part SMAJ24A/TR13; LCSC Part C90510
D2: 5V ESD; SOD-323_L1.7-W1.3-LS2.5-BI; LCSC Part C19224
F1: PTC(40R); F0603; Manufacturer Part JK-SMD0603-001; LCSC Part C2687114
H1, H3: LAIL-PZ2.54-4P-L; pad-4; Manufacturer Part LAIL-PZ2.54-4P-L; LCSC Part C54950602; not fitted
H2: PZ254V-11-05P; pad-5; Manufacturer Part PZ254V-11-05P; LCSC Part C492404; not fitted
J1, J2, J3, J4: 1.8mm螺丝孔; pad; not fitted
L1: 10uH/920mA; IND-SMD_L3.0-W3.0_SWPA3010S; Manufacturer Part SWPA3015S100MT; LCSC Part C45403
Q1: MMBT3906; SOT-23; LCSC Part C727128
R1: 75K; R0402; LCSC Part C144737
R2, R10, R11, R12, R13, R17, R18, R21, R22, R23, R24, R25, R26: 51R; R0402; LCSC Part C137960
R3: 100K; R0402; LCSC Part C25741
R4: 30K; R0402; LCSC Part C25776
R5: 51R; R0603; LCSC Part C2907181
R6: 24K; R0402; LCSC Part C138026
R7, R8, R15, R16, R19: 10K; R0402; LCSC Part C25744
R9, R32: 0R; R0402; LCSC Part C60485
R14: 1K; R0402; LCSC Part C11702
R20: 51R; R0402; LCSC Part C137960; not fitted
R27, R28, R30: 10k; R0402; LCSC Part C25744
R29: 20k; R0402; LCSC Part C25765
R31: 100k; R0402; LCSC Part C25741
R33: 0R; R0402_Jumper; LCSC Part C60485; not fitted
U1: ETA2845S2G_C22362741; SOT-23-6_L2.9-W1.6-P0.95-LS2.8-BR; Manufacturer Part ETA2845S2G; LCSC Part C22362741
U2: GD32F303CCT6; LQFP-48_L7.0-W7.0-P0.50-LS9.0-BL; Manufacturer Part GD32F303CCT6; LCSC Part C116151
U3: LSM6DSV16XTR; LGA-14_L3.0-W2.5-P0.50-BR; Manufacturer Part LSM6DSV16XTR; LCSC Part C5267406
U4: SN74LVC1G126DBVR; SOT-23-5; LCSC Part C46472327
U5: SN74LVC1G125DBV; SOT-23-5; LCSC Part C3040625
U6: ME6211C18M5G-N; SOT-23-5_L3.0-W1.7-P0.95-LS2.8-BR; Manufacturer Part ME6211C18M5G-N; LCSC Part C236671
X1: XL2EL89CSI-111YLC-12M; CRYSTAL-SMD_4P-L3.2-W2.5-BL; Manufacturer Part XL2EL89CSI-111YLC-12M; LCSC Part C5280576

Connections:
+1.8VA: C21.2, R32.1, U6.5 (VOUT)
+3.3V: C1.2, C5.2, C7.2, C12.1, C13.2, C14.2, C16.2, C18.2, C19.2, C20.2, H1.1, H2.2, L1.2, Q1.2 (E), R1.2, R7.1, R8.2, R9.2, R15.2, R16.2, R20.2, R27.2, R30.2, R31.2, R33.2, U2.1 (VBAT), U2.24 (VDD_1), U2.36 (VDD_2), U2.48 (VDD_3), U3.5 (Vdd_IO), U4.5 (VCC), U5.5 (VCC), U6.1 (VIN), U6.3 (CE)
+BATT: C6.2, CN1.2, CN2.2, D1.1 (K), H3.4, R3.2, U1.5 (IN)
/DATA: CN1.3, CN2.1, F1.1
/DATA1: R5.2, R31.1, U4.4, U5.2
/DEBUG_RX: R7.2, R10.1, U2.43 (PB7)
/DEBUG_TX: R11.1, U2.42 (PB6)
/GD_OSCIN: C10.2, U2.5 (PD0-OSCIN), X1.1
/GD_OSCOUT: C11.2, U2.6 (PD1-OSCOUT), X1.3
/GD_RST: C8.2, R8.1, R14.1, U2.7 (NRST)
/GD_SWDCLK: R12.1, R15.1, U2.37 (PA14)
/GD_SWDIO: R13.1, R16.1, U2.34 (PA13)
/IMU_INT1: R25.2, U3.4 (INT1)
/IMU_INT2: R26.2, U3.9 (INT2)
/IMU_SPI_CLK: R22.2, U3.13 (SCL)
/IMU_SPI_CS: C17.2, R21.2, U3.12 (CS)
/IMU_SPI_MISO: R23.2, U3.1 (SDO/SA0)
/IMU_SPI_MOSI: R24.2, U3.14 (SDA)
/PA2_USART1_TX: R27.1, R28.1, U2.12 (PA2), U4.2
/PA3_USART1_RX: R30.1, U2.13 (PA3), U5.4
/PA4_SPI0_NSS: R21.1, U2.14 (PA4)
/PA5_SPI0_SCK: R22.1, U2.15 (PA5)
/PA6_SPI0_MISO: R23.1, U2.16 (PA6)
/PA7_SPI0_MOSI: R24.1, U2.17 (PA7)
/PB0: R25.1, U2.18 (PB0)
/PB1: R26.1, U2.19 (PB1)
/TXD_EN: C22.2, Q1.3 (C), R29.2, U4.1, U5.1
/USB_DM: H3.3, R17.2
/USB_DP: H3.2, R18.2
GND: C5.1, C6.1, C7.1, C8.1, C9.1, C10.1, C11.1, C12.2, C13.1, C14.1, C15.1, C16.1, C17.1, C18.1, C19.1, C20.1, C21.1, C22.1, CN1.1, CN2.3, D1.2 (A), D2.1, H1.2, H2.3, H3.1, R4.2, R6.1, R19.1, R29.1, U1.2 (GND), U2.8 (VSSA), U2.23 (VSS_1), U2.35 (VSS_2), U2.47 (VSS_3), U3.2 (SDx/AH1/Qvar1), U3.3 (SCx/AH2/Qvar2), U3.6 (GND), U3.7 (GND), U4.3 (GND), U5.3 (GND), U6.2 (VSS), X1.2 (GND), X1.4 (GND)
unnamed: C2.1, R2.2
unnamed: D2.2, F1.2, R5.1
unnamed: H1.3, R10.2
unnamed: H1.4, R11.2
unnamed: H2.1, R14.2
unnamed: H2.4, R13.2
unnamed: H2.5, R12.2
unnamed: Q1.1 (B), R28.2
unnamed: R2.1, U1.1 (BST)
unnamed: R3.1, R4.1, U1.4 (EN)
unnamed: C1.1, R1.1, R6.2, U1.3 (FB)
unnamed: C2.2, L1.1, U1.6 (SW)
unnamed: R19.2, R33.1, U2.44 (BOOT0)
unnamed: R17.1, U2.32 (PA11)
unnamed: R18.1, U2.33 (PA12)
unnamed: C9.2, R9.1, U2.9 (VDDA)
unnamed: C15.2, R20.1, R32.2, U3.8 (Vdd)

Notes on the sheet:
UVLO=3V
Debug
二选一，手工焊接
SWD
USB Download
改6.3V
USB Download Switch

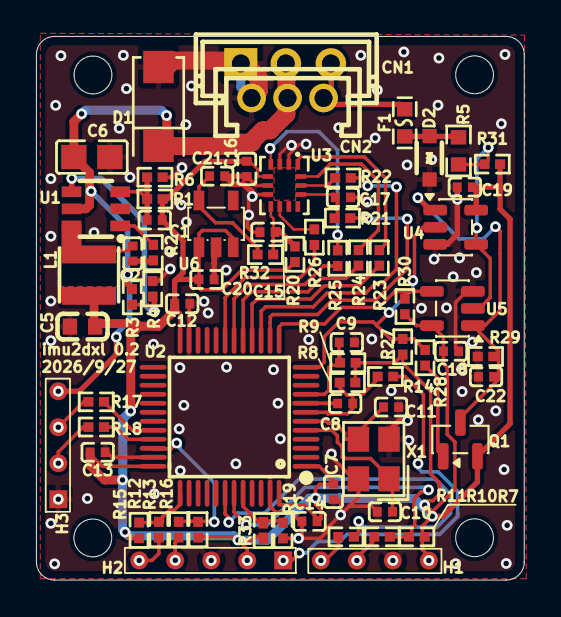
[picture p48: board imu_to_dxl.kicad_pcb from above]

Board: 2 copper layers, 27.1 x 30.2 mm, 74 parts (0 on the bottom side), 47 nets.

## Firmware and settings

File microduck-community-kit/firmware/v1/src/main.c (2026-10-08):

/*!
    \file    main.c
    \brief   imu_to_dxl v1: main loop

    The protocol responses no longer run here at all - a frame is parsed in the
    USART interrupt and its reply goes out over DMA, because a `sync_read` burst
    gives this node one reply slot (~295 us) to start answering.  What is left
    for the main loop is the sensor, the register image (dev_refresh), the
    deferred-reply timer, housekeeping, and one number worth watching: how long
    an iteration takes, since that is now the only thing that can delay a reply
    that is waiting for its slot.
*/

#include "board.h"

#include "app_header.h"
#include "bus.h"
#include "dbg.h"
#include "dev.h"
#include "imu.h"
#include "imu_math.h"
#include "imu_sim.h"
#if IMU_USE_SPI
#include "imu_spi.h"
#endif
#include "systick.h"
#include "us_time.h"

#define STATS_PERIOD_MS     2000U
#define LED_ACTIVE_MS       500U
#define LED_IDLE_MS         125U
#define LED_IDLE_AFTER_MS   5000U

#if STATUS_LED_ENABLE
static uint8_t s_led_on;
#endif

/* worst main-loop iteration since the last stats line; a long one is the only
   thing that can make a deferred reply miss its slot */
static uint32_t s_loop_max_us;

static void board_gpio_init(void)
{
#if STATUS_LED_ENABLE
    rcu_periph_clock_enable(RCU_GPIOB);
    gpio_init(LED_GPIO, GPIO_MODE_OUT_PP, GPIO_OSPEED_50MHZ, LED_PIN);
    gpio_bit_reset(LED_GPIO, LED_PIN);
#endif

    /* IMU pins: chip select driven high so a fitted sensor stays deselected
       while no SPI driver is running.  SCK/MOSI/MISO are left as inputs. */
    rcu_periph_clock_enable(RCU_GPIOA);
    rcu_periph_clock_enable(RCU_GPIOB);
    gpio_init(IMU_SPI_GPIO, GPIO_MODE_OUT_PP, GPIO_OSPEED_50MHZ, IMU_CS_PIN);
    gpio_bit_set(IMU_SPI_GPIO, IMU_CS_PIN);
    gpio_init(IMU_SPI_GPIO, GPIO_MODE_IN_FLOATING, GPIO_OSPEED_50MHZ,
              IMU_SCK_PIN | IMU_MISO_PIN | IMU_MOSI_PIN);
    gpio_init(IMU_INT1_GPIO, GPIO_MODE_IPU, GPIO_OSPEED_50MHZ,
              IMU_INT1_PIN | IMU_INT2_PIN);
}

static void led_tick(uint32_t now_ms)
{
#if STATUS_LED_ENABLE
    static uint32_t next_ms;
    uint32_t idle = bus_ms_since_rx(BUS_PORT_MIRROR, now_ms);
    uint32_t period = (idle > LED_IDLE_AFTER_MS) ? LED_IDLE_MS : LED_ACTIVE_MS;

    if (0U == next_ms) {
        next_ms = now_ms + period;
    }
    if ((int32_t)(now_ms - next_ms) >= 0) {
        next_ms = now_ms + period;
        s_led_on = (uint8_t)(0U == s_led_on);
        if (s_led_on) {
            gpio_bit_set(LED_GPIO, LED_PIN);
        } else {
            gpio_bit_reset(LED_GPIO, LED_PIN);
        }
    }
#else
    (void)now_ms;
#endif
}

/*! \brief how many transactions this node has answered on either port.

    Used as the "somebody is talking to us" signal that lets a trial image
    confirm itself after BOOT_CONFIRM_MS instead of waiting twice as long. */
static uint32_t bus_answered_total(void)
{
    bus_stats_t mirror;
    bus_stats_t main_port;

    bus_get_stats(BUS_PORT_MIRROR, &mirror);
    bus_get_stats(BUS_PORT_MAIN, &main_port);
    return mirror.answered + main_port.answered;
}

static const char *proto_name(uint8_t p)
{
    switch (p) {
    case PROTO_DXL: return "dxl2.0";
    case PROTO_FEE: return "feetech";
    default:        return "none";
    }
}

#if !IMU_USE_SPI
static const char *sim_name(uint8_t m)
{
    switch (m) {
    case SIM_STATIC:    return "static";
    case SIM_SINE:      return "sine";
    case SIM_DRIFT:     return "drift";
    case SIM_NOISE:     return "noise";
    case SIM_SPIN:      return "spin";
    case SIM_SFLP_WAIT: return "sflp-wait";
    case SIM_FROZEN:    return "frozen";
    default:            return "?";
    }
}
#endif

static void stats_print(uint32_t now_ms)
{
    static uint32_t next_ms;
    const imu_sample_t *s = imu_latest();
    const dev_cfg_t *cfg = dev_cfg();
    bus_stats_t m;
    bus_stats_t d;

    if (0U == next_ms) {
        next_ms = now_ms + STATS_PERIOD_MS;
    }
    if ((int32_t)(now_ms - next_ms) < 0) {
        return;
    }
    next_ms = now_ms + STATS_PERIOD_MS;

    bus_get_stats(BUS_PORT_MIRROR, &d);
    bus_get_stats(BUS_PORT_MAIN, &m);
    DBG_INFO("t=%u temp=%uC sensor=%s samples=%u qvalid=%u",
             (unsigned)(now_ms / 1000U), (unsigned)dev_temp_celsius(),
             imu_is_simulated() ? "sim" : "spi", (unsigned)imu_samples(),
             (unsigned)((s->flags & TELEM_FLAG_SFLP_VALID) != 0U));
#if IMU_USE_SPI
    DBG_INFO("  lsm6dsv16x who=0x%02X present=%u sflp_words=%u ovr=%u badtag=%u probe_fail=%u",
             (unsigned)imu_spi_whoami(), (unsigned)imu_spi_present(),
             (unsigned)imu_spi_sflp_words(), (unsigned)imu_spi_fifo_overruns(),
             (unsigned)imu_spi_bad_tags(), (unsigned)imu_spi_probe_fails());
#else
    DBG_INFO("  sim mode=%s amp=%u freq=%u",
             sim_name(cfg->sim_mode), (unsigned)cfg->sim_amp,
             (unsigned)cfg->sim_freq);
#endif
    DBG_INFO("  cfg id(dxl=%u fee=%u) baud(dxl=%u fee=%u console=%u) frame=%s lock=%s dirty=0x%02X",
             (unsigned)cfg->dxl_id, (unsigned)cfg->fee_id,
             (unsigned)uart_port_get_baud(bus_uart(BUS_PORT_MAIN)),
             (unsigned)dev_fee_baud(),
             (unsigned)uart_port_get_baud(bus_uart(BUS_PORT_MIRROR)),
             (cfg->report_frame ? "trunk" : "chip"), proto_name(cfg->proto_lock),
             (unsigned)dev_image(PROTO_DXL)[DXL_VENDOR_ADDR + V_STATUS]);
    DBG_INFO("  uart0 rx=%u tx=%u dropped=%u err=%u echo=%u frames=%u answered=%u proto=%s",
             (unsigned)d.rx_bytes, (unsigned)d.tx_bytes, (unsigned)d.rx_dropped,
             (unsigned)d.rx_errors, (unsigned)d.echoed, (unsigned)d.frames,
             (unsigned)d.answered, proto_name(d.last_proto));
    DBG_INFO("  uart1 rx=%u tx=%u dropped=%u err=%u echo=%u frames=%u answered=%u proto=%s",
             (unsigned)m.rx_bytes, (unsigned)m.tx_bytes, (unsigned)m.rx_dropped,
             (unsigned)m.rx_errors, (unsigned)m.echoed, (unsigned)m.frames,
             (unsigned)m.answered, proto_name(m.last_proto));
    DBG_INFO("  bus held=%u/%u lost=%u gaps=%u ignored=%u loop_max=%uus",
             (unsigned)d.deferred, (unsigned)m.deferred,
             (unsigned)(d.tx_lost + m.tx_lost), (unsigned)(d.gaps + m.gaps),
             (unsigned)(d.ignored + m.ignored), (unsigned)s_loop_max_us);
    s_loop_max_us = 0U;
    {
        /* integer millidegrees/s: nano.specs does not format floats unless
           -u _printf_float is linked, and the console does not need them */
        long gx = (long)lroundf_i32((float)s->gyro[0] * IMU_GYRO_MDPS_PER_LSB);
        long gy = (long)lroundf_i32((float)s->gyro[1] * IMU_GYRO_MDPS_PER_LSB);
        long gz = (long)lroundf_i32((float)s->gyro[2] * IMU_GYRO_MDPS_PER_LSB);
        DBG_INFO("  block gyro(mdps) %ld %ld %ld accel(mg) %ld %ld %ld",
                 gx, gy, gz,
                 (long)lroundf_i32((float)s->accel[0] * IMU_ACCEL_MG_PER_LSB),
                 (long)lroundf_i32((float)s->accel[1] * IMU_ACCEL_MG_PER_LSB),
                 (long)lroundf_i32((float)s->accel[2] * IMU_ACCEL_MG_PER_LSB));
        DBG_INFO("  block quat(xyzh) %04X %04X %04X flags 0x%02X cnt=%u",
                 (unsigned)s->quat[0], (unsigned)s->quat[1], (unsigned)s->quat[2],
                 (unsigned)s->flags, (unsigned)s->counter);
    }
}

int main(void)
{
    uint32_t last_seq;
    uint32_t now;
    uint32_t boot_check_ms = 0U;

#if (APP_SLOT == 1)
    SCB->VTOR = SLOT_A_BASE;
#elif (APP_SLOT == 2)
    SCB->VTOR = SLOT_B_BASE;
#endif

    systick_config();
    us_time_init();
    board_gpio_init();
    bus_init();
    dbg_bind(bus_uart(BUS_PORT_MIRROR));
    dbg_init();

    dev_init();
    imu_init();
    dev_refresh();

    last_seq = dev_cfg_seq();
    bus_apply_ports();

    DBG_INFO("%s fw %u.%u", FW_BUILD_NAME, FW_VERSION_MAJOR, FW_VERSION_MINOR);
    DBG_INFO("dxl id=%u (v2.0, block at %u), feetech id=%u (block at %u)",
             (unsigned)dev_cfg()->dxl_id, (unsigned)DXL_TELEM_ADDR,
             (unsigned)dev_cfg()->fee_id, (unsigned)FEE_TELEM_ADDR);
    DBG_INFO("bus uart1=%u baud, mirror uart0=%u baud, sensor=%s",
             (unsigned)uart_port_get_baud(bus_uart(BUS_PORT_MAIN)),
             (unsigned)uart_port_get_baud(bus_uart(BUS_PORT_MIRROR)),
             imu_is_simulated() ? "simulated" : "lsm6dsv16x/spi0");
#if IMU_USE_SPI
    DBG_INFO("sensor frame=%s, vendor bias reg %u; gyro +-500dps @ %.1f mdps/LSB",
             dev_cfg()->report_frame ? "trunk" : "chip",
             (unsigned)(DXL_VENDOR_ADDR + V_BIAS_X_L),
             (double)IMU_GYRO_MDPS_PER_LSB);
#else
    DBG_INFO("sim mode=%s - write vendor reg %u (magic I M, cmd) to change",
             sim_name(dev_cfg()->sim_mode), (unsigned)(DXL_VENDOR_ADDR + V_SIM_MODE));
#endif
    {
        const app_header_t *own = app_own_header();
        if (NULL != own) {
            DBG_INFO("image v%u.%u.%u in slot %c, header %s",
                     (unsigned)APP_VERSION_MAJOR(own->image_version),
                     (unsigned)APP_VERSION_MINOR(own->image_version),
                     (unsigned)APP_VERSION_PATCH(own->image_version),
                     (SLOT_A == app_own_slot()) ? 'A' : 'B',
                     (APP_HDR_OK == app_own_header_check()) ? "valid" : "invalid");
        } else {
            DBG_INFO("development image (no bootloader, no header)");
        }
        DBG_INFO("boot state: slot=%d trial=%d attempts=%u stay=%u pingpong=%u",
                 (int)dev_boot_boot_slot(), (int)dev_boot_trial_slot(),
                 (unsigned)0, (unsigned)dev_boot_stay(),
                 (unsigned)dev_boot_pingpong());
    }

    while (1) {
        uint32_t loop_start_us = us_now();
        uint32_t samples;
        uint32_t took_us;

        now = systick_get_ms();

        imu_tick(now);

        /* Publish the register image as soon as the sensor has a new sample,
           and a few times a second regardless so the fields that drift on their
           own (the MCU temperature, the free-running tick) stay current.  The
           reads themselves run in the USART interrupt and must not touch the
           ADC or the vendor window, which is why this lives here. */
        {
            static uint32_t last_samples;
            static uint32_t last_publish_ms;
            samples = imu_samples();
            if ((samples != last_samples) || ((uint32_t)(now - last_publish_ms) >= 50U)) {
                last_samples = samples;
                last_publish_ms = now;
                dev_refresh();
            }
        }

        bus_poll(now);
        {
            /* The automatic config save waits for both ports to be quiet: a
               flash page erase stalls the core for tens of ms, and on the real
               robot that would eat a control-loop tick. */
            uint32_t idle_a = bus_ms_since_rx(BUS_PORT_MIRROR, now);
            uint32_t idle_b = bus_ms_since_rx(BUS_PORT_MAIN, now);
            dev_tick(now, (idle_a < idle_b) ? idle_a : idle_b);
        }

        if (dev_cfg_seq() != last_seq) {
            last_seq = dev_cfg_seq();
            bus_apply_ports();
#if IMU_USE_SPI
            DBG_INFO("config applied: id=%u/%u frame=%s baud=%u console=%u",
                     (unsigned)dev_cfg()->dxl_id, (unsigned)dev_cfg()->fee_id,
                     dev_cfg()->report_frame ? "trunk" : "chip",
                     (unsigned)uart_port_get_baud(bus_uart(BUS_PORT_MAIN)),
                     (unsigned)uart_port_get_baud(bus_uart(BUS_PORT_MIRROR)));
#else
            DBG_INFO("config applied: id=%u/%u sim=%s baud=%u console=%u",
                     (unsigned)dev_cfg()->dxl_id, (unsigned)dev_cfg()->fee_id,
                     sim_name(dev_cfg()->sim_mode),
                     (unsigned)uart_port_get_baud(bus_uart(BUS_PORT_MAIN)),
                     (unsigned)uart_port_get_baud(bus_uart(BUS_PORT_MIRROR)));
#endif
        }

        /* Trial images confirm themselves once they have run long enough
           (docs/flash_layout.md §4.4); checked once a second, not every loop. */
        if ((int32_t)(now - boot_check_ms) >= 0) {
            boot_check_ms = now + 1000U;
            if (dev_boot_tick(now, bus_answered_total())) {
                DBG_INFO("this trial image is now confirmed");
            }
        }

        led_tick(now);
        stats_print(now);

        /* High-water mark of one iteration.  A deferred reply is sent from
           here, so this is the number that says whether the main loop can still
           keep the bus contract (the target is well under a reply slot). */
        took_us = us_elapsed(loop_start_us, us_now());
        if (took_us > s_loop_max_us) {
            s_loop_max_us = took_us;
        }

        if (dev_reboot_pending(now)) {
            DBG_INFO("reboot requested");
            delay_1ms(2U);
            NVIC_SystemReset();
        }
    }
}

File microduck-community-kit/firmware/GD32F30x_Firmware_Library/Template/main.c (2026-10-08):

/*!
    \file    main.c
    \brief   led spark with systick, USART print and key example

    \version 2026-2-6, V3.0.3, firmware for GD32F30x
*/

/*
    Copyright (c) 2025, GigaDevice Semiconductor Inc.

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
    1. Redistributions of source code must retain the above copyright notice, this 
       list of conditions and the following disclaimer.
    2. Redistributions in binary form must reproduce the above copyright notice, 
       this list of conditions and the following disclaimer in the documentation 
       and/or other materials provided with the distribution.
    3. Neither the name of the copyright holder nor the names of its contributors 
       may be used to endorse or promote products derived from this software without 
       specific prior written permission.

    THIS SOFTWARE IS PROVIDED BY THE COPYRIGHT HOLDERS AND CONTRIBUTORS "AS IS" 
AND ANY EXPRESS OR IMPLIED WARRANTIES, INCLUDING, BUT NOT LIMITED TO, THE IMPLIED 
WARRANTIES OF MERCHANTABILITY AND FITNESS FOR A PARTICULAR PURPOSE ARE DISCLAIMED. 
IN NO EVENT SHALL THE COPYRIGHT HOLDER OR CONTRIBUTORS BE LIABLE FOR ANY DIRECT, 
INDIRECT, INCIDENTAL, SPECIAL, EXEMPLARY, OR CONSEQUENTIAL DAMAGES (INCLUDING, BUT 
NOT LIMITED TO, PROCUREMENT OF SUBSTITUTE GOODS OR SERVICES; LOSS OF USE, DATA, OR 
PROFITS; OR BUSINESS INTERRUPTION) HOWEVER CAUSED AND ON ANY THEORY OF LIABILITY, 
WHETHER IN CONTRACT, STRICT LIABILITY, OR TORT (INCLUDING NEGLIGENCE OR OTHERWISE) 
ARISING IN ANY WAY OUT OF THE USE OF THIS SOFTWARE, EVEN IF ADVISED OF THE POSSIBILITY 
OF SUCH DAMAGE.
*/

#include "gd32f30x.h"
#include "systick.h"
#include <stdio.h>
#include "main.h"
#include "gd32f307c_eval.h"

/*!
    \brief      toggle the led every 500ms
    \param[in]  none
    \param[out] none
    \retval     none
*/
void led_spark(void)
{
    static __IO uint32_t timingdelaylocal = 0U;

    if(timingdelaylocal){

        if(timingdelaylocal < 500U){
            gd_eval_led_on(LED2);
        }else{
            gd_eval_led_off(LED2);
        }

        timingdelaylocal--;
    }else{
        timingdelaylocal = 1000U;
    }
}

/*!
    \brief      main function
    \param[in]  none
    \param[out] none
    \retval     none
*/

int main(void)
{
#ifdef __FIRMWARE_VERSION_DEFINE
    uint32_t fw_ver = 0U;
#endif

    /* configure systick */
    systick_config();
    /* initialize the LEDs, USART and key */
    gd_eval_led_init(LED2); 
    gd_eval_led_init(LED3); 
    gd_eval_led_init(LED4);
    gd_eval_com_init(EVAL_COM0);
    gd_eval_key_init(KEY_WAKEUP, KEY_MODE_GPIO);
    
    /* print out the clock frequency of system, AHB, APB1 and APB2 */
    printf("\r\nCK_SYS is %d", rcu_clock_freq_get(CK_SYS));
    printf("\r\nCK_AHB is %d", rcu_clock_freq_get(CK_AHB));
    printf("\r\nCK_APB1 is %d", rcu_clock_freq_get(CK_APB1));
    printf("\r\nCK_APB2 is %d", rcu_clock_freq_get(CK_APB2));

#ifdef __FIRMWARE_VERSION_DEFINE
    fw_ver = gd32f30x_firmware_version_get();
    /* print firmware version */
    printf("\r\nGD32F30x series firmware version: V%d.%d.%d", (uint8_t)(fw_ver >> 24U), (uint8_t)(fw_ver >> 16U), (uint8_t)(fw_ver >> 8U));
#endif /* __FIRMWARE_VERSION_DEFINE */

    while (1){
        if(RESET == gd_eval_key_state_get(KEY_WAKEUP)){
            gd_eval_led_on(LED3);
            delay_1ms(500U);
            gd_eval_led_off(LED3);
            gd_eval_led_toggle(LED4);
        }
    }
}

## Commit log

2026-09-29 chore: initialize duck-robot project
    Include parallel Microduck reference projects, hardware assets, build documentation, training baselines and validation evidence. Add root ignore rules for local environments, caches and credentials.
    [ankle_dbl_block__configuration_right.scad, ankle_dbl_block__configuration_right.stl, ankle_l_v1.stl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]
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2026-10-08 hardware: import banana_pcb community battery adapter board
    [banana_pcb.kicad_pcb, banana_pcb.kicad_sch]
2026-10-08 feat: add jlc-order tool for JLC open-platform PCB ordering
    - JOP HMAC-SHA256 signing verified byte-for-byte against official doc example
    - stdlib-only CLI: doctor / file upload / pcb quote|order|reorder|quick / order get|progress / ledger
    - gerber zip validation (banana_pcb package passes), order params template
    - safety: interactive confirm for orders, no auto-retry on order creation,
    dry-run never sends, secrets redacted, local orders.jsonl ledger (gitignored)
    - 33 tests (auth golden vectors, fake-transport client, CLI gates) + ruff clean
2026-10-08 docs: record 2026-10-09 progress and restore reference repos to upstream
    - add PROGRESS.md: hardware arrivals (bus servo adapter, buck module, IMU2DXL v1.0, HAT V1.1, all servos, printed parts) with follow-up todos; direction set to community-kit Feetech route
    [ankle_left.stl, ankle_right.stl, banana_pcb.kicad_pcb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]
2026-10-08 hardware: archive confirmed schematics and prepare Feetech firmware flash kit
    - docs/schematics/: new archive for confirmed-hardware designs - ScrapMeta imu_to_dxl v0.3 (eprj2 source @aa4c32d + netlist + both exported sheets, correct v0.3 page identified by J1+J3+BM07) and Radxa HAT V1.1 (5-page PDF)
    [100ask-openjtag.cfg, 8devices-lima.cfg, actux3.cfg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]
2026-10-08 docs: annotate imu_to_dxl board photo with per-component functions
    Callout labels for U1/U2/U3/U6, J1/J3/J2, passive zone, Y1, mounting holes and version silkscreen, plus full component-function legend. Notes physical silkscreen reads IMU2DXL V1.0 vs repo's v0.3 wor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
2026-10-09 feat(jlc-order): real API paths, order capability, first production order
    - align all 14 PCB endpoints extracted from official SDK jars (quote/order/
    reorder/progress/list), verified live against the gateway
    - implement pcb order/quick: [order] config section (pcbFileUrl, contact,
    invoice, express), advancePayment=false default (manual pay, no auto charge)
    - order-time pitfalls handled: charFontColor required, invoiceType=personal
    for personal invoices, expressType JYM rejected (use SF_DSBZ_JF),
    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
2026-10-09 docs: archive photos (multimeter/PSU/buck module), annotate parts, record no-load test
    - docs/photos: permanent archive of user photos from WXWork cache + README
    registry; annotated buck-module front (v2) and back (v4, DC-jack
    misID corrected per physical check)
    - docs/buck-module-test.md: BUS SERVO POWER SUPPLY V1.3 no-load scan —
    VOLT_SEL bridged 6V, regulation knee ~6.3V (dropout-tracking below),
    PWR OUT = battery pass-through; 2S verdict: usable at worst-case sag
    6.6V (6.00V held); next: re-solder 5V before IMU (LDO max 5.5V)
    - scripts/annotate_buck_module.py: annotation generator
    - PROGRESS/BOM: tool photos registry, buck module findings, meter arrived
2026-10-09 docs: finalize power architecture (buck module = IMU 5V + battery junction)
    - topology: battery -> banana_pcb -> power board; PWR OUT (pass-through)
    feeds HAT +BATT (onboard AP63205 -> 5V MCU, servo ports out +BATT to
    bus chain x15 HD-1910); VCC (5V after re-solder) feeds IMU branch
    - IMU wiring rules from netlist: J1 leaf-node only (never inline the
    8.4V bus, LDO max 5.5V), hybrid 3P cable (GND/DATA from bus, VBATT
    from VCC 5V), J2 +3V3 is reference not power input
    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
2026-10-10 docs: route audit — rewrite root BOM for Feetech line, archive route-A BOM
    Audit of main docs for pre-route-decision (pre-2026-10-09) leftovers:
    - BOM.md rewritten as active Feetech-route BOM per power-architecture v2
    (battery-direct bus, IMU direct on bus, power board optional, add 5A
    fuse + charger as open purchase items, HAT V1.2, NP-F550 battery)
    - original route-A BOM (2026-09-28, XL330/OpenRB/Pi Zero) archived
    verbatim to docs/bom-route-a-20260928.md
    - README: route-status paragraph now points to arch v2; Robot Overview
    and Build Plan sections marked as route-A baseline (content kept)
    - PROJECT_KNOWLEDGE: IMU version corrected (v0.3 confirmed), old-machine
    banner on trainin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
2026-10-10 docs: rewrite root README for route C, archive route-A baseline
    - root README now leads with the Feetech (route C) mainline: hardware
    summary, power v2, BOM, jlc-order ordering tool, flash entry
    - move route-A steps (phases 0-7), XL330/OpenRB constraints, sim/image
    audit notes and 2026-09-28 verification disclaimer to
    docs/route-a-baseline-20260928.md (verbatim archive, all links valid)
    - drop stale placeholder sections and old-machine WSL path notes
    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
2026-10-10 chore: 将三个上游参考库归入 references 目录
    保持参考库内部内容和许可不变，同步项目规则、目录导航、文档链接及辅助脚本路径。记录迁移证据，保留历史验收路径和原始导入哈希。验证4239个文件迁移前后SHA-256一致、4146个Git文件纯重命名、152个修改文档链接有效，以及Bash语法和HEX离线校验。
    [ankle_dbl_block__configuration_right.scad, ankle_dbl_block__configuration_right.stl, ankle_l_v1.stl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]
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2026-10-10 docs: 补录Microduck并修正开源社区选样遗漏
    新增官方预售与交期、软件训练架构、社区教程和五仓公开快照证据，明确运动角色与DIY生态价值，不将stars或排产压力当销量。增加X11图鉴和主视觉，同步41卡234编号及媒体索引；内容审查、链接和生成测试通过。
2026-10-11 docs: HAT A-section continuity checks all pass, servo-line AMP2.0 adapter plan
    - A1-A5 unpowered verification results (2026-10-11): servo pinout matches
    V1.0, +BATT entry = back pad row 3/4, header pin1 located via GND sweep,
    GD32F303 not on servo data lines, supercap discharged
    - Connector finding: HD-1910 stock lead is AMP2.0-3P (2.0mm), fits none of
    the three boards (EH 3P / 5264-3P); bench workaround = crossed dupont
    leads, final plan = re-crimp EH housings
    - Archive 7 annotated photos + register in photos README, add annotate
    script, replace hat back photo with clearer shot
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2026-10-13 docs: Radxa TF 卡烧录记录——镜像校验通过、自研脚本两次失败弃用、改用 Rufus
    - 镜像 radxa-zero3_debian_bullseye_cli_b6.img SHA512 与官方一致
    - 卡为 1TB SDXC（原 exFAT 空卡）；直写脚本两次在 ~66MB 处失败，疑似写入未落卡
    - 按用户要求弃用自研烧录/测试脚本，改用 Rufus 4.15 标准工具，判读标准与后续步骤落盘
    - PROGRESS.md Radxa 条目同步更新
2026-10-13 docs: SD 烧录记录更新——Rufus 因 SCSI 总线不可用改用 balenaEtcher，补登 10-11 实测照片
    - 烧录记录：复查推翻「WriteFile 假成功未落卡」疑点（卡分区表已变 GPT，前 66MB 确实写入）；Rufus 不识别内置读卡器（BusType=SCSI）弃用，改用 balenaEtcher 2.1.7 便携版，判读标准与下一步同步改写；PROGRESS 到货行同步勘误
    - 照片登记：2026-10-11 A 段实测轮次遗留未登记的用户 HAT 背面照 2（_user-back2）、5 张局部放大裁剪图及 V1.0 原理图 5 页导出图（docs/photos/sch/），内容按文件名与生成时间推断，未复核对象标待确认
    - 工具：收录 3 个只读诊断脚本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
2026-10-13 docs: 主控 eMMC 线刷成功（路线A），TF 卡路线暂停留悬案
    - 新增 emmc-flash-radxa-zero3w-20261013 专题：官方工具链落位（RKDevTool v2.86/驱动/loader，dl.radxa.com 源）、镜像本机重下并 SHA512 验证、DriverInstall 假成功需 pnputil 手动装 rockusb.inf、首次下载Boot失败为一次性抖动重试即过、最终日志"下载镜像成功"（2.55GB 完整写入）
    - sd-flash 专题降为历史：TF 路线放弃，~66MB 写入失败根因留悬案；首次开机前须拔 TF 卡（TF 启动优先）
    - PROGRESS 增 2026-10-13 路线A条目；tools/emmc-flash/ 入 .gitignore
    - 待验证：独立供电开机、进系统通路（HDMI/串口/SSH）、HA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
2026-10-13 fix: 勘误 eMMC 线刷记录——尚未成功，系误读截图
    - v2.96 实际失败于"切换存储到SPINOR"：镜像行存储列被设为 SPINOR，板上无 SPI NOR，切换必败，镜像未写入
    - 撤回此前"烧录成功/开机出登录提示"的错误结论（befc480 措辞有误，历史不改写，以本提交为准）
    - 修正方法已记录：镜像行存储列下拉改 EMMC 后重执行
2026-10-13 docs: eMMC 线刷确认成功——镜像行存储列 SPINOR→EMMC 后全流程通过
    - 最终生效配置：EMMC + loader v1.10.111 + 镜像 0x0 + 强制按地址写（2026-10-13 用户确认）
    - 教训入库：v2.96 每行存储列是活动下拉值，重建表格后须逐行核对
    - PROGRESS 同步为线刷成功；待验证：拔 TF 卡首次上电、radxa 登录、配网
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2026-10-13 docs: 串口挂点定位——DDR 初始化训练中挂死（四次上电表现+判读），eMMC boot 区可读、DDR 颗粒嫌疑最大；修 serial-log.py 落盘 flush bug，日志整理归档
2026-10-13 fix: serial-log.py 增加掉线自动重连与逐行 flush——对抗 DAPLink 假在线（COM3 枚举保持但 ClearCommError 报错）
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2026-10-15 feat: 增加离屏录像脚本并修正策略回放统计口径
    - scripts/record_video.py：passive(HOME 静置)/policy(策略回放) 两种离屏 MP4 录制
    - 模型加 offscreen 帧缓冲声明（800x600）
    - 修正回放统计：此前打印的是累计帧数，误读为存活递增；各回合真实存活约 0.2s
    - videos/ 加入忽略（录像不入库）
2026-10-15 fix: 执行器 v0.1 补反电动势限速——修复仿真关节速度超物理上限 66 倍
    - 用户观看策略回放指出动作超速；量化：旧 position 执行器无速度上限，
    策略关节速度峰值 792 rad/s，BAM 推算舵机空载上限 vin/kt≈11.9 rad/s @7.4V
    - 改为 motor 力矩源 + 环境内一阶电机模型（电压环/反电动势/电阻）：
    速度钳至 10.9 rad/s，力矩饱和 kt·vin/R≈0.94 N·m；KV=200 V/rad 自选待整定
    - 同轮修复 XML joint 未引用 default class，armature/frictionloss 此前未生效
    - 复测：静置 10s 偏差<0.003rad；阶跃 0.5rad 峰值 7.35 rad/s、90% 100ms，
    与舵机规格量级一致；录像重录（video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
2026-10-16 feat: 站立策略训练成功——v0.2 动作尺度修正后 100 万步收敛
    - 诊断：恒零动作在扰动下本就活满 10s（最优解=输出 0），致命的是策略
    输出的高频目标抖动（±0.05rad 抖动 0.9s 即摔；EMA 低通无效）
    - v0.2：ACTION_SCALE 0.5→0.1 + log_std_init=-1.9（有效抖动 ±0.015rad，
    与初始扰动同量级），随机基线 0.5s→1.7s，PPO 9 分钟 ep_len 11→1000+
    - 验收：确定性策略 10/10 回合活满 10s（upright>0.996、z≈HOME）；
    3 倍扰动（0.045rad 关节+0.12rad 倾斜）5/5 活满
    - 补上此前未生效的回合 10s 截断（truncated 恒 False）；录像重录
    - 仅仿真成果，不构成实物行为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
2026-10-16 feat: 站立 v0.2.2 安静站立——目标指令 EMA 低通消除高频乱动
    - 用户指出 v0.2 策略持续乱动：环境无持续干扰，乱动来自策略自身高频
    输出（每步|Δa|≈0.32，目标角每步跳 ±0.03rad@50Hz，关节摆 2.7°/步）
    - v0.2.1 加大平滑惩罚无效（压的是探索方差，存活反降至 60%），废弃
    - v0.2.2 目标指令 EMA 低通（α=0.25，~60ms，近似舵机固件斜率限制，
    训练/部署一致）：高频指令物理性失效，PPO 收敛到输出恒 0
    - 验收：10/10 活满 10s、3 倍扰动 5/5 活满、每步|Δa|=0.000（安静站立）
    - 修复 step() 返回 truncated 硬编码 False 致回合截断从未生效的 b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
2026-10-17 docs: HAT 舵机总线排障——Radxa 侧清白（fiq 修复+回环 PASS），收敛到 HAT 74LVC 驱动；U-Boot 短接自锁发现
2026-10-17 fix: feetech-ping 校验和公式错误——正常应答全被判无效；B5 单舵机 ping 通（ID1 在线）
    - checksum_ok 误写 sum==0xFF，正确为 ~sum==末字节；修复后 ID1 应答 0x00
    - 双真凶定案：工具 bug + 第一颗舵机信号脚拖线（挂线 1V，换后 3.4V）
    - 勘误：HAT 74LVC 正常（前'故障域 HAT'作废）；'接触不良'归因部分不成立
    - 工具已同步板上 ~/feetech-ping.py
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2026-10-17 docs: 装配对位调研——上游仅要求归中位装配，对位标准为孔位对齐而非视觉垂直（修正会话推断）
2026-10-19 feat: v0.8/v0.9 终局——命令采样 bug 考古修复、相位辅助验证、EMA 终局证伪
    - v0.8：发现 v0.6 系列全部训练 vx_cmd 采样被行尾注释吞掉（命令恒 0）；
    修复+相位节律先验（49 维观测+相位-抬脚耦合）后仍不位移——命令 bug 非根因
    - v0.9：去 EMA 全面崩溃（存活 0-20%）——EMA 是行走/站立共同的必需学习缓冲
    - 19 轮约 1.35 亿步架构组合穷尽；步态需上游级课程工程或 MJX 重构
    - 成果定格：安静站立/推扰主动恢复/全命令档动态稳定 100%（v0.8 终版）；
    env 回滚 v0.8 配置；录像已更新
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2026-10-19 feat: mjlab 路线 GPU 物理管线闭环——自建 XML+自写奖励 4096 环境 130k steps/s
    - WSL 装齐 B 线锁定组合（mjlab 1.3.0/mujoco 3.10.0/mujoco-warp 3.8.1/
    warp 1.12.0；坑：mjlab 漏声明 scipy、mujoco-warp 3.9.1 删 ls_parallel 接口）
    - 管线适配：TerrainEntityCfg(plane)、spec.delete 删 XML motor 由
    IdealPdActuatorCfg 接管（stiffness 25/damping 2/effort 0.94+ BAM armature/摩擦）
    - smoke：ManagerBasedRlEnv GPU 闭环 129,950 env-steps/s@4096 env
    （CPU SubprocVecEnv 的 8.7 倍）；环境构建 4.3s
    - 剩余：完整 DuckWalk 环境（命令/推扰/相位）+训练入口+验收
2026-10-19 feat: mjlab 首训全面达标——速度误差<0.02、全档存活 95-100%、3N 等效推扰 100%
    - 完整 DuckWalk mjlab 环境（mjlab_duck/：命令 25% 零档/速度域随机推扰/
    全套自设计奖励与终止）+ rsl_rl PPO 训练入口 + 验收脚本 eval_mjlab
    - 4096 env×10000 迭代 3.4h（RTX 4080 WSL）；reward 1.1→~34
    - 验收：±0.2 档误差 0.005-0.018（CPU 版 1/10 以上）、全档存活 19-20/20、
    3N 等效速度脉冲满额率 100/100（门槛 80%）
    - 修正 19 轮 CPU 归因：瓶颈是 CPU MuJoCo 引擎+样本规模而非动作空间
    （512 env CPU 与 8 env 同瓶颈，GPU warp 引擎本质不同）
    - 自建边界保持：环境/奖励/命令全自设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
2026-10-20 docs: 核实舵机归中装配与中位校准风险
    区分预先转到2048与CAL校准，记录大偏移、反馈窗口及旧目标使能的证据边界，并修正装配与进度入口。归档HLS内存表和SCS协议原文，保持原始字节。文档链接、原文校验及自写文档diff检查通过；厂商原文14行尾部空白原样保留。未操作实物。
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2026-10-21 feat: 完善 MuJoCo 实时工作台与精细模型显示
    新增单环境 mjlab 回放入口、中文控制界面、位姿显示与独立碰撞视图；复用有来源和许可说明的精细网格，保留训练物理与策略接口。修复旧 CPU 回放启动和节拍问题，归档界面、性能及物理一致性验证，并记录 native 软件渲染低速限制。
2026-10-21 feat: 手掰行程检查收官——servo-trace 记录器+3D 数字孪生 viewer；四轮实测定案 12/22/32 自由关节(32 限 ±2.356 rad)、23 汇总算法勘误为原值差值法；bench-tools 过期零位表述与编号修正

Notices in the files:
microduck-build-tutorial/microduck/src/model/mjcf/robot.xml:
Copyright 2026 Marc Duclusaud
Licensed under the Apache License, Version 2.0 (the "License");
